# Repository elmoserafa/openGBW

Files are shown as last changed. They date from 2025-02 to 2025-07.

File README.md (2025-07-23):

# Differences to sybutter's openGBW:
- back to using ESP32 DevKit V1

# Recent Changes & Fixes (July 2025)

## Platform Migration
- **Hardware**: Migrated from ESP32-C3 to ESP32 DevKit v1
- **Pin Configuration**: Updated all GPIO pin assignments for ESP32 DevKit v1 compatibility
- **Build System**: Updated PlatformIO configuration for esp32dev board

## Rotary Encoder Improvements
- **Fixed Input Detection**: Resolved issue where rotary encoder input was not being registered
- **Enhanced Responsiveness**: Improved encoder sensitivity for precise value setting
- **Precision Tuning**: Calibrated encoder to provide exact 0.1g increments for weight adjustment and 0.01g for offset adjustment
- **Wake on Input**: Added wake functionality for both encoder rotation and button press when screen is asleep
- **Debugging**: Added comprehensive serial output for encoder troubleshooting

## Technical Fixes
- **GPIO Compatibility**: Changed encoder button pin from GPIO 34 to GPIO 27 (supports pull-up resistors)
- **Interrupt Handling**: Added manual interrupt attachment for reliable encoder operation
- **Pin Configuration**: Implemented proper INPUT_PULLUP modes for encoder pins
- **Menu Navigation**: Enhanced menu system responsiveness and accuracy
- **Grinder Control**: Added support for NPN transistor control of 5V grinder signals that need to be pulled to ground

## Documentation Updates
- **Wiring Tables**: Updated all pin assignments to match ESP32 DevKit v1
- **Component References**: Changed hardware references from ESP32-C3 to ESP32 DevKit v1
- **Troubleshooting**: Added encoder calibration and debugging information

-----------

# Differences to jb-xyz's openGBW:
 Extends https://github.com/jb-xyz/openGBW

 - Commented the code and added some more structure to it all
 - Cup weight now has an escape to it as well as a confirmation screen to subvert the escape
 - Info menu to see offset and cup weight
 - Wake on rotary turn
 - Sleep adjustable via menus instead of code compile
 - Now uses XIAO-ESP32-C3
 - Added the ability to use a button as a grinder trigger

-----------

# OpenGBW

This Project extends and adapts the original by Guillaume Besson

More info: https://besson.co/projects/coffee-grinder-smart-scale

This mod will add GBW functionality to basically any coffe grinder that can be started and stopped manually.

The included 3D Models are adapted to the Eureka Mignon XL and the Macap Leo E but the electronics can be used for any Scale.

-----------

### Getting started

1) 3D print the included models for a Eureka Mignon XL or design your own
2) flash the firmware onto an ESP32 DevKit v1
3) connect the display, relay, load cell and rotary encoder to the ESP32 according to the wiring instructions
4) go into the menu by pressing the button of the rotary encoder and set your initial offset. -2g is a good enough starting value for a Mignon XL
5) if you're using the Mignon's push button to activate the grinder set grinding mode to impulse. If you're connected directly to the motor relay use continuous.
6) if you only want to use the scale to check your weight when single dosing, set scale mode to scale only. This will not trigger any relay switching and start a timer when the weight begins to increase. If you'd like to build your own brew scale with timer, this is also the mode to use.
7) calibrate your load cell by placing a 100g weight on it and following the instructions in the menu
8) set your dosing cup weight
5) exit the menu, set your desired weight and place your empty dosing cup on the scale. The first grind might be off by a bit - the accuracy will increase with each grind as the scale auto adjusts the grinding offset

-----------

### Wiring

#### Load Cell

| Load Cell  | HX711 | ESP32  |
|---|---|---|
| black  | E-  | |
| red  | E+  | |
| green  | A+  | |
| white  | A-  | |
| | VCC  | VCC/3.3 |
| | GND  | GND |
| | SCK  | GPIO 17/TX2|
| | DT  | GPIO 16/RX2| 

#### Display

| Display | ESP32 |
|---|---|
| VCC | VCC/3.3 |
| GND | GND |
| SCL | GPIO 22 |
| SDA | GPIO 21 |

#### Grinder Control

**Option 1: Direct Relay Control**
| Relay | ESP32 | Grinder |
|---|---|---|
| + | VCC/3.3 | |
| - | GND | |
| S | GPIO 35 | |
| Middle Screw Terminal | | push button |
| NO Screw Terminal | | push button |

**Option 2: NPN Transistor Control (for 5V signal that needs to be pulled to ground)**
| Component | Connection |
|---|---|
| Resistor (1kΩ) | GPIO 33 → NPN Base |
| NPN Emitter | GND |
| NPN Collector | Grinder 5V signal line |
| Grinder 5V+ | Grinder power supply |

*When ESP32 GPIO 33 goes HIGH → NPN turns ON → Pulls 5V signal to ground → Grinder starts*  
*When ESP32 GPIO 33 goes LOW → NPN turns OFF → 5V signal stays high → Grinder stops*

#### Rotary Encoder

| Encoder | ESP32 |
|---|---|
| VCC/+ | VCC/3.3 |
| GND | GND |
| SW | GPIO 27 |
| DT | GPIO 32 |
| CLK | GPIO 23 |

### MX Cherry Switch

One side to GPIO 25 
one side to GND

-----------

### BOM

1x ESP32 DevKit v1  
1x HX711 load cell amplifier  
1x 0.9" OLED Display  
1x KY-040 rotary encoder  
1x 500g load cell 60 x 15,8 x 6,7 https://www.amazon.de/gp/product/B019JO9BWK/ref=ppx_yo_dt_b_asin_title_o02_s00?ie=UTF8&psc=1  

**Grinder Control Options:**
- Option 1: 1x 5V single channel relay (for direct relay control)
- Option 2: 1x NPN transistor (2N2222, BC547, or similar) + 1x 1kΩ resistor (for 5V signal control)

Various jumper cables I would recommend shielded cables  
A few WAGO or similar connectors

-----------

### 3D Files

You can find the 3D STL models on thangs.com

Eureka XL: https://thangs.com/designer/jbear-xyz/3d-model/Eureka%20Mignon%20XL%20OpenGBW%20scale%20addon-834667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

These _should_ fit any grinder in the Mignon line up as far as I can tell.

There's also STLs for a universal scale in the repo, though it is mostly meant as a starting off point to create your own. You can use the provided files, but you'll need to print an external enclosure for the ESP32, relay and any other components your setup might need.

-----------

### PCB

This PCB was designed using the many resources in EAF and an absolute crap ton of youtube. KiCad is truly amazing. 

If you want to just **get the pcb** made:
The **openGBW_pcbv1.3FF.zip** is the zipped file you'll want to send to PCBWay/JLCPCB 

If you want to **modify and remix** the pcb:
The **openGBW_v1.3_proj.zip** is the file you'll want to download

This was done in KiCad as well. 

The PCB requires that you solder the ESP32 DevKit v1 to the board. It also makes use of JST-XH connectors on the outward connections. 

-----------

### Troubleshooting

#### Rotary Encoder Issues

**Problem**: Encoder button works but rotation is not detected
- **Solution**: Check wiring connections to GPIO 23 (CLK) and GPIO 32 (DT)
- **Debugging**: Monitor serial output at 115200 baud for encoder delta values

**Problem**: Encoder is unresponsive or requires many clicks to change values
- **Solution**: Encoder sensitivity has been calibrated for standard KY-040 encoders
- **Technical**: Each physical detent now provides exactly 0.1g increment for weight and 0.01g for offset

**Problem**: Values jump in large increments instead of precise steps
- **Solution**: Recent firmware updates have fixed precision issues
- **Verification**: Check serial monitor for "Weight:" and "Offset:" debug messages

**Problem**: Encoder input not registered at all
- **Potential Causes**: 
  - GPIO 34 cannot be used for buttons (input-only, no pull-up support)
  - Missing pull-up resistors on encoder pins
  - Incorrect interrupt configuration
- **Solutions**: 
  - Use GPIO 27 for encoder button (has pull-up support)
  - Ensure proper INPUT_PULLUP pin modes
  - Verify manual interrupt attachment in code

#### General Hardware Issues

**Problem**: Scale readings are unstable
- **Solution**: Ensure load cell is properly mounted and HX711 connections are secure
- **Calibration**: Use the menu system to calibrate with a known 100g weight

**Problem**: Display not working
- **Solution**: Check I2C connections on GPIO 21 (SDA) and GPIO 22 (SCL)
- **Power**: Verify 3.3V power supply to display

-----------

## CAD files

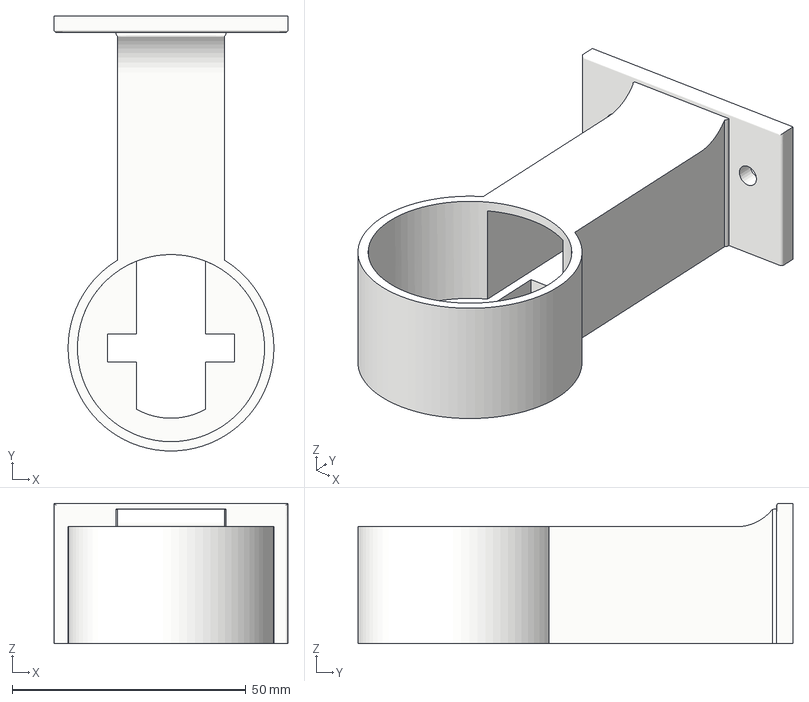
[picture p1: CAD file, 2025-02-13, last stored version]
3D/Macap Leo E/openGBW - LoadCellHolder - Long v4.3mf
50.0 x 93.0 x 30.0 mm

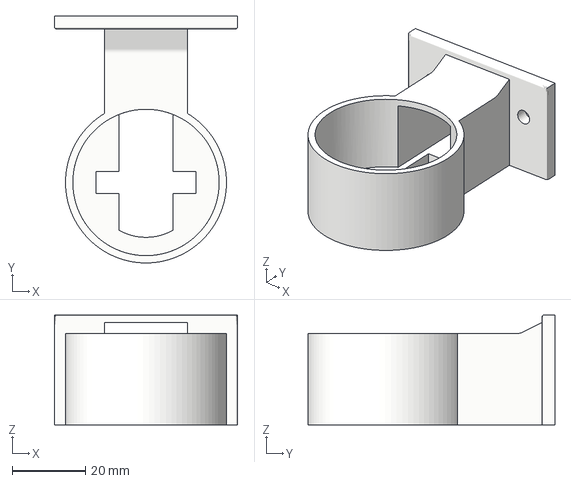
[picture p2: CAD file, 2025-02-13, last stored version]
3D/Macap Leo E/openGBW - LoadCellHolder - Short v1.3mf
50.0 x 67.4 x 30.0 mm

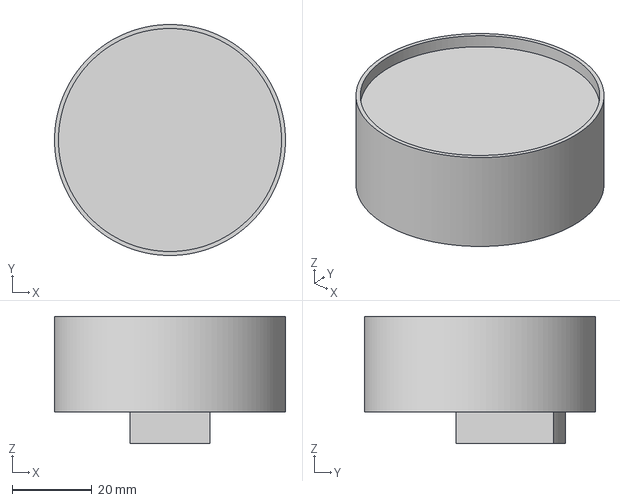
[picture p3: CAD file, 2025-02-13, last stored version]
3D/Macap Leo E/openGBW - DosingCupPlate v13.3mf
58.0 x 58.0 x 32.0 mm

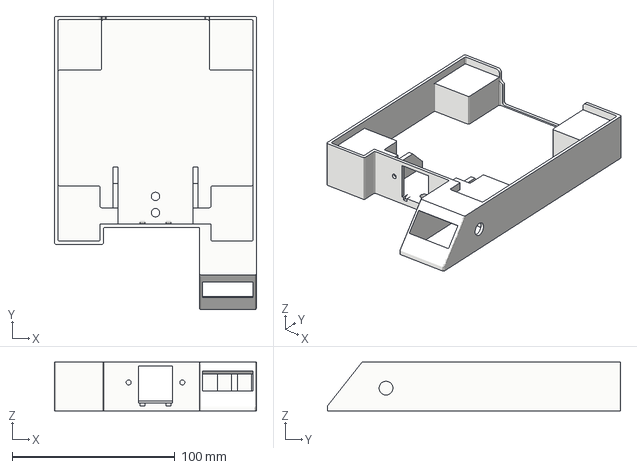
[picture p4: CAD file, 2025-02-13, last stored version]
3D/Macap Leo E/openGBW - Base v7.3mf
124.0 x 180.0 x 30.0 mm

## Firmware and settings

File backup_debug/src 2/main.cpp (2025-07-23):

#include <Arduino.h>
#include "HX711.h"

// Pin definitions (from full firmware)
#define LOADCELL_DOUT_PIN  19
#define LOADCELL_SCK_PIN   18

HX711 loadcell;


// Global variables (declare only once)
unsigned long sampleCount = 0;
unsigned long lastRatePrint = 0;
unsigned long lastSampleCount = 0;
float scaleFactor = 1409.88f; // Standard scale factor
bool calibrated = false;

void setup() {
    Serial.begin(115200);
    loadcell.begin(LOADCELL_DOUT_PIN, LOADCELL_SCK_PIN);
    Serial.println("Place the scale on a stable surface and ensure it is unloaded.");
    delay(2000);
    Serial.println("Taring... Please wait.");
    loadcell.tare();
    Serial.println("Tare complete. Place a 100g weight on the scale and type 'c' in the serial monitor to calibrate.");
}


void calibrateScale() {
    Serial.println("\n--- Calibration Start ---");
    Serial.println("Remove all weight from the scale. Press ENTER in the serial monitor to tare.");
    // Wait for ENTER
    while (!Serial.available()) {
        delay(10);
    }
    while (Serial.available()) Serial.read(); // clear buffer
    loadcell.tare();
    Serial.println("Tare complete. Place your calibration weight on the scale and enter its value in grams, then press ENTER.");
    // Wait for user to enter weight value
    String input = "";
    while (input.length() == 0) {
        if (Serial.available()) {
            input = Serial.readStringUntil('\n');
            input.trim();
        }
        delay(10);
    }
    float knownWeight = input.toFloat();
    if (knownWeight <= 0.0f) {
        Serial.println("Invalid weight entered. Calibration aborted.");
        return;
    }
    Serial.print("Calibrating with weight: ");
    Serial.print(knownWeight, 2);
    Serial.println(" g");
    long reading = loadcell.get_value(10); // average 10 readings with weight
    if (reading == 0) {
        Serial.println("Calibration failed: reading is zero.");
        return;
    }
    scaleFactor = (float)reading / knownWeight;
    calibrated = true;
    Serial.print("Calibration complete. Scale factor: ");
    Serial.println(scaleFactor, 4);
    Serial.println("--- Calibration End ---\n");
}

void loop() {
    static unsigned long lastSampleTime = 0;
    unsigned long now = millis();

    // Check for serial input to trigger calibration or print scale factor
    if (Serial.available()) {
        char cmd = Serial.read();
        if (cmd == 'c' || cmd == 'C') {
            calibrateScale();
        } else if (cmd == 's' || cmd == 'S') {
            Serial.print("Current scale factor: ");
            Serial.println(scaleFactor, 4);
        }
    }

    if (now - lastSampleTime >= 100) { // 100 ms interval = 10 Hz
        lastSampleTime = now;
        if (loadcell.is_ready()) {
            sampleCount++;
            long raw = loadcell.get_value(1);
            Serial.print("Sample: ");
            Serial.print(sampleCount);
            Serial.print(" | is_ready: YES");
            Serial.print(" | Raw ADC: ");
            Serial.print(raw);
            if (calibrated && scaleFactor != 0.0f) {
                float grams = (float)raw / scaleFactor;
                Serial.print(" | Grams: ");
                Serial.print(grams, 2);
            }
            Serial.println();
        } else {
            Serial.print("Sample: ");
            Serial.print(sampleCount);
            Serial.println(" | is_ready: NO | Raw ADC: HX711 not found.");
        }
    }

    if (now - lastRatePrint >= 1000) {
        unsigned long samplesInLastSec = sampleCount - lastSampleCount;
        Serial.print("Measured sample rate: ");
        Serial.print(samplesInLastSec);
        Serial.println(" Hz");
        lastSampleCount = sampleCount;
        lastRatePrint = now;
    }
}

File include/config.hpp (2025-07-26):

#pragma once

#include <SimpleKalmanFilter.h>
#include "HX711.h"
#include <MathBuffer.h>
#include <AiEsp32RotaryEncoder.h>
#include <Preferences.h>
#include <MathBuffer.h>
#include <SPI.h>
#include <U8g2lib.h>

// Declarations of global variables (no memory allocation here)
extern Preferences preferences;       // Preferences object
extern HX711 loadcell;                // HX711 load cell object
extern SimpleKalmanFilter kalmanFilter; // Kalman filter for smoothing weight measurements

extern TaskHandle_t ScaleTask;        // Task handle for the scale task
extern TaskHandle_t ScaleStatusTask;  // Task handle for the scale status task

class MenuItem
{
    public:
        int id;
        bool selected;
        char menuName[16];
        double increment;
        double *value;
};

//Set your sleep variable
#define SLEEP_AFTER_MS 60000

//Main Variables and Pins
#define STATUS_EMPTY 0
#define STATUS_GRINDING_IN_PROGRESS 1
#define STATUS_GRINDING_FINISHED 2
#define STATUS_GRINDING_FAILED 3
#define STATUS_IN_MENU 4
#define STATUS_IN_SUBMENU 5
#define STATUS_INFO_MENU 8

#define CUP_WEIGHT 70
#define CUP_DETECTION_TOLERANCE 5 // 5 grams tolerance above or bellow cup weight to detect it

#define LOADCELL_DOUT_PIN 16
#define LOADCELL_SCK_PIN 17

#define LOADCELL_SCALE_FACTOR 1409.88

#define TARE_MEASURES 20 // use the average of measure for taring
#define SIGNIFICANT_WEIGHT_CHANGE 5 // 5 grams changes are used to detect a significant change
#define COFFEE_DOSE_WEIGHT 18
#define COFFEE_DOSE_OFFSET -2.5
#define MAX_GRINDING_TIME 20000 // 20 seconds diff
#define GRINDING_FAILED_WEIGHT_TO_RESET 150 // force on balance need to be measured to reset grinding

#define GRINDER_ACTIVE_PIN 14

#define GRIND_BUTTON_PIN 25
#define DEFAULT_GRIND_TRIGGER_MODE true  // true = use button, false = cup detection
#define AUTO_OFFSET_ADJUSTMENT true     // Enable automatic offset adjustment after grinding

#define TARE_MIN_INTERVAL 10 * 1000 // auto-tare at most once every 10 seconds

#define ROTARY_ENCODER_A_PIN 23
#define ROTARY_ENCODER_B_PIN 32
#define ROTARY_ENCODER_BUTTON_PIN 27
#define ROTARY_ENCODER_VCC_PIN -1
#define ROTARY_ENCODER_STEPS 4

// Screen 
#define OLED_SDA 21
#define OLED_SCL 22

// External User Variables
extern volatile bool displayLock; // Add this declaration
extern double scaleWeight;
extern unsigned long scaleLastUpdatedAt;
extern unsigned long lastSignificantWeightChangeAt;
extern unsigned long lastTareAt;
extern bool scaleReady;
extern int scaleStatus;
extern double cupWeightEmpty;
extern unsigned long startedGrindingAt;
extern unsigned long finishedGrindingAt;
extern double setWeight;
extern double offset;
extern bool scaleMode;
extern bool grindMode;
extern bool greset;
extern int menuItemsCount;
extern double setCupWeight;
extern MenuItem menuItems[];
extern int currentMenuItem;
extern int currentSetting;
extern int currentSubmenu; // 0 = main menu, 1 = mode submenu, 2 = config submenu
extern int currentSubmenuItem;
extern int modeMenuItemsCount;
extern int configMenuItemsCount;
extern MenuItem modeMenuItems[];
extern MenuItem configMenuItems[];
extern int sleepTime;
extern bool screenJustWoke;
extern unsigned int shotCount;
extern bool useButtonToGrind;
extern bool showingTaringMessage;
extern unsigned long taringMessageStartTime;
extern bool manualGrindMode;

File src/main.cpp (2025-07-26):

#include <Arduino.h>
#include <WiFi.h>
#include <PubSubClient.h>
#include <ESPAsyncWebServer.h>

#include "display.hpp"
#include "scale.hpp"
#include "config.hpp"
#include "web_server.hpp"

// Definitions of global variables (memory allocated here)
Preferences preferences;             // Preferences object
HX711 loadcell;                      // HX711 load cell object
SimpleKalmanFilter kalmanFilter(0.02, 0.02, 0.01); // Kalman filter for weight smoothing

TaskHandle_t ScaleTask = nullptr;    // Initialize task handles to nullptr
TaskHandle_t ScaleStatusTask = nullptr;

volatile bool displayLock = false; 

void setup() {
    Serial.begin(115200);
    
    // Deactivate WiFi and Bluetooth on ESP32 startup
    WiFi.mode(WIFI_OFF);
    WiFi.disconnect(true);
#ifdef ARDUINO_ARCH_ESP32
    btStop();
#endif
    // Setup other components
    setupDisplay();
    setupScale();
    // setupWebServer(); // Disabled
}

void loop() {
    delay(1000);
}

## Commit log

2024-12-26 User adjustable sleep timer in menu
2024-12-26 No longer changes set wait on rotary wake
    [config.hpp, rotary.cpp]
2024-12-27 failed mode exits with rotary turn
    [config.hpp, rotary.cpp]
2025-01-12 fixed the sleep menu
    [rotary.cpp, scale.cpp]
2025-02-13 Added 3mf files for macap leo e
    [openGBW - Base v7.3mf, openGBW - DosingCupPlate v13.3mf, openGBW - LoadCellHolder - Long v4.3mf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]
2025-02-13 Made it based around the seeed studio xiao-esp32-c3
2025-05-17 Added a switch start and modified pcb for it
2025-05-18 wake on button click
2025-07-15 adapted for ESP32 devkit V1 (TEST1)
2025-07-15 changed grinder activation to use NPN transistor instead of relay
2025-07-17 encoder fix
2025-07-17 grinder off logic fix
    [scale.cpp]
2025-07-23 debug version
    [Scale Addon - Base.step, Scale Addon - Dosing cup Holder.step, Scale Addon - Load Cell - DONT PRINT ONLY FOR REFERENCE.step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]
2025-07-23 limit scale to 10hz
2025-07-23 set to relay, new pins
2025-07-26 freezing during grinding fix
    [config.hpp, scale.cpp]
